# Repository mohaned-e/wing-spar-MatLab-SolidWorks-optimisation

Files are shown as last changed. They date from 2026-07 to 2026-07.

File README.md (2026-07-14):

# Automated Wing Spar Design: MATLAB Structural Optimisation with SolidWorks FEA Validation

An automated tool that designs a minimum-mass, geometrically-valid box spar for a foam-board UAV wing — sizing it against bending, torsion, and the real NACA aerofoil envelope — then validates the result against SolidWorks FEA.

Built as a self-directed project by an Aerospace Engineering undergraduate at the University of Manchester, extending a university structural design exercise (originally taught using a manual Excel spreadsheet and hand iteration) into a fully automated MATLAB pipeline.

---

## Background: from manual design to automation

This project began as a manual, hand-iterated structural design exercise — sizing a wing spar in Excel by adjusting dimensions until the stress and torsion checks passed, then building and physically load-testing the result. That original project is documented here:

**[▶ Original manual Wing Spar Design — physical build & load test](https://youtu.be/0Efimh8G1TI?si=opNGgLY5TrZkc-P6)**

Every constraint and validation check in this automated MATLAB version (bending stress, torsional compliance, geometric fit, physical safety margin) traces directly back to lessons learned building and testing that first version by hand.

---

## What this project does

Given a target wing (span, aerofoil, load case), the tool:

1. **Models the bending moment** distribution along the wing under a specified load factor.
2. **Sizes a hollow box-section spar** — height, width, and wall thickness — searching thousands of candidate cross-sections to find the **lightest one** that satisfies:
   - Bending stress (reserve factor ≥ 1)
   - Torsional stiffness (twist compliance ≤ 3°/N·m)
   - **Fits inside the real NACA aerofoil shape**, across the spar's full width — not just at a single point
   - A genuine manufacturing safety margin (real, physical clearance — not a mathematical edge case)
3. **Generates the aerofoil geometry from scratch** using the standard NACA 4-digit equations (thickness distribution + camber line + perpendicular surface offset) — no external aerofoil coordinate database used.
4. **Exports the aerofoil coordinates** in a format SolidWorks can import directly (`Insert → Curve → Curve Through XY Points`).
5. **Calculates the spar's exact position** — both chordwise and vertically — accounting for the aerofoil's camber, so the spar sits correctly inside the wing rather than being naively centred on the chord line.
6. **Validates the design against SolidWorks FEA**, comparing MATLAB's analytical predictions (deflection, bending stress) against a real finite element simulation of the built geometry.

---

## Repository structure

```
/matlab/
    wing_spar_optimisation.m         — main optimiser (bending + torsion + aerofoil fit)
    NACA_airofoil_coordinates.m      — NACA 4-digit aerofoil generator & SolidWorks export
    local_aerofoil_height.m          — aerofoil upper/lower surface height at a given chord position
/solidworks/
    Wing_Geometry_Master_Sketch.SLDPRT
    Rib.SLDPRT
    Spar.SLDPRT
    Rear_Spar.SLDPRT
    leading_edge.SLDPRT
    Flaps.SLDPRT
    Spar_holder.SLDPRT
    wing_assembly.SLDASM
/aerofoil_data/
    naca4418.txt                     — exported aerofoil coordinates (tab-delimited X Y Z, for SolidWorks import)
/results/
    Full_Wing_Design.png
    Aerofoil_Graph.png
    Bending_Displacment_Test.png
    Bending_Stress_Test.png
    Torisional_Stress_test.png
README.md
```

---

## Methodology

### 1. Structural model
The wing is modelled as a cantilever beam, fixed at the root, carrying a point load at the tip (`load factor × aircraft mass × g / 2`). The spar is a hollow rectangular box section; bending stress, tip deflection, and torsional twist are calculated from standard beam theory (second moment of area, Bredt-Batho thin-wall torsion theory).

### 2. Optimisation
A nested search over height, width, top/bottom wall thickness, and side wall thickness finds the lightest cross-section that passes all structural checks *and* physically fits inside the aerofoil. Wall thickness was deliberately included as a free variable rather than fixed — the optimiser correctly converged on the material's minimum manufacturable thickness (5mm foam board) in every case, consistent with the general aerospace engineering principle that thin-walled sections are structurally efficient (material is placed as far as possible from the neutral axis, rather than adding mass near the centre where it contributes little to stiffness). This is a genuine, expected result rather than an unused design variable — see "Known limitations" for the one check (local buckling) that would be needed to make thickness a meaningful trade-off rather than always bottoming out.

### 3. Aerofoil geometry
The NACA 4-digit thickness and camber equations are implemented directly (not pulled from a lookup table), including the correct perpendicular offset of the thickness distribution relative to the camber line — a detail that's easy to get wrong by simply adding thickness vertically instead of normal to the curve.

### 4. Geometric fit validation
An early version of the optimiser checked whether the spar fit the aerofoil at a single chordwise point. This was found — through direct visual inspection in SolidWorks — to be insufficient: because the aerofoil tapers away from its point of maximum thickness, a wide spar's *corners* can clip the surface even when its centre clears comfortably. The constraint was rebuilt to check the aerofoil envelope across the spar's full width, taking the tightest top and bottom limits independently (which can come from different edges of the spar).

---

## Results: MATLAB prediction vs. SolidWorks FEA

Final design: **38mm × 92mm** box spar, 5mm walls, positioned 90mm from the leading edge and 8.88mm above the chord line, tested over a 755mm free (unsupported) length.

| Quantity | MATLAB predicted | SolidWorks FEA (actual) | Note |
|---|---|---|---|
| Tip deflection (6.74N tip load) | 19.86 mm | 20.6 mm | Close agreement — **3.7% difference** |
| Peak bending stress (6.74N tip load) | 357.4 kPa | 538.9 kPa* | 50.8% higher — local effect, see below |
| Torsional twist (10 N·m reference torque) | ≤30° (design limit, not a point prediction) | 10° | Real design sits well inside the limit, see below |

\* *The FEA peak stress occurs at the vice grip interface at the root — a local stress concentration from the clamping mechanism that simple beam theory does not model. Deflection, a whole-beam property averaged over the full structure, is far less sensitive to this kind of local effect and shows strong agreement; stress, being highly local, diverges specifically at this known geometric discontinuity. This is consistent with the failure location predicted qualitatively in the source structural design methodology this project extends.*

**On the torsion result**: the optimiser doesn't target 30° as a predicted outcome — it's the *compliance limit* (≤3°/N·m at the reference 10 N·m torque) the design is required to satisfy, and the optimiser deliberately searches for the lightest spar that sits right at that boundary (calculated compliance ≈2.999°/N·m, essentially on the limit by design). The measured real-world twist (10°) is roughly 3x lower than that worst-case limit — a reassuring result, not a discrepancy to explain away. The gap itself is attributable to the analytical torsion model (Bredt-Batho thin-wall theory) being a conservative approximation: it assumes an idealised infinitely-thin wall, whereas the real wall thickness is a non-trivial fraction of the section (13% of the height), which stiffens the real structure beyond what the thin-wall formula accounts for. Being wrong in this direction — predicting more twist than actually occurs — is the safe direction for a structural design margin to be wrong in.

Spar mass was cross-checked against SolidWorks' own mass properties calculation: once the difference in physical length was accounted for (MATLAB assumed a full-span length for its mass estimate; the SolidWorks test-rig spar was built to the full foam board sheet length for practical clamping purposes), the predicted mass-per-unit-length matched SolidWorks' reported value to six significant figures — confirming the cross-sectional geometry transferred from MATLAB into CAD with no error.

---

## Known limitations / not yet implemented

- **Local panel buckling is not modelled.** The optimiser checks material stress and torsional stiffness, but not whether the thin top/bottom panels could buckle (a stability failure) before the material stress limit is reached. Given the optimiser already converges on the thinnest available wall thickness, this is the most significant open extension to this project — likely via a SolidWorks Buckling study on the final geometry, since implementing a panel buckling formula analytically would require additional assumptions this project doesn't currently make (panel aspect ratio, edge support conditions).
- **The torsional twist angle was measured directly off the deformed model** (viewed straight down the twist axis, true-scale deflection) rather than via a SolidWorks angular displacement output, so it should be treated as a good estimate rather than an instrument-grade measurement.

---

## Requirements

- MATLAB (no additional toolboxes required — `fminsearch`/manual search loops only, `writematrix` requires R2019a+)
- SolidWorks (used for geometry import, assembly, and FEA — Student Edition sufficient)

## Author

Mohaned Elkurdi — MEng Aerospace Engineering, University of Manchester

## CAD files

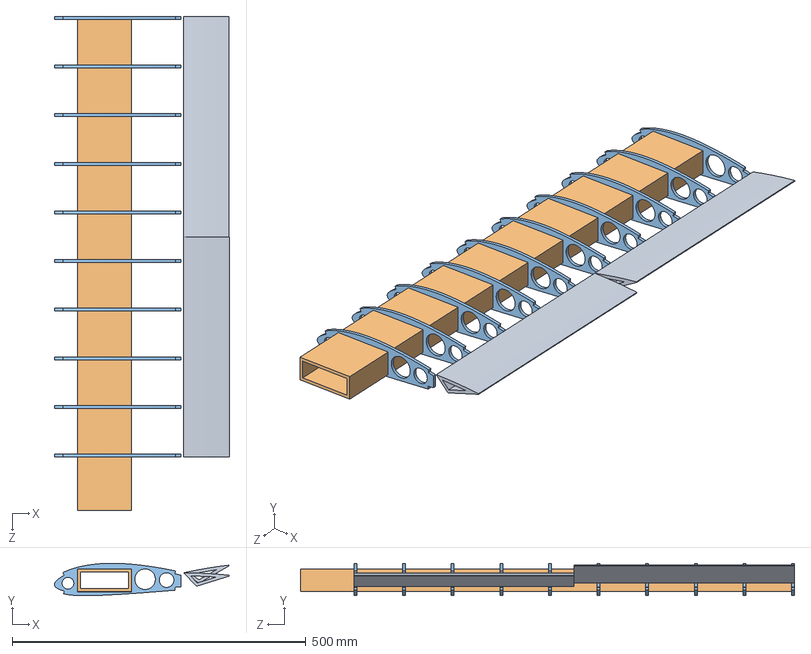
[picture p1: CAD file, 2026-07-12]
solidworks/Wing_Assembly.SLDASM
298.5 x 55.3 x 841.0 mm
Rib x 10
Spar
Flaps x 2

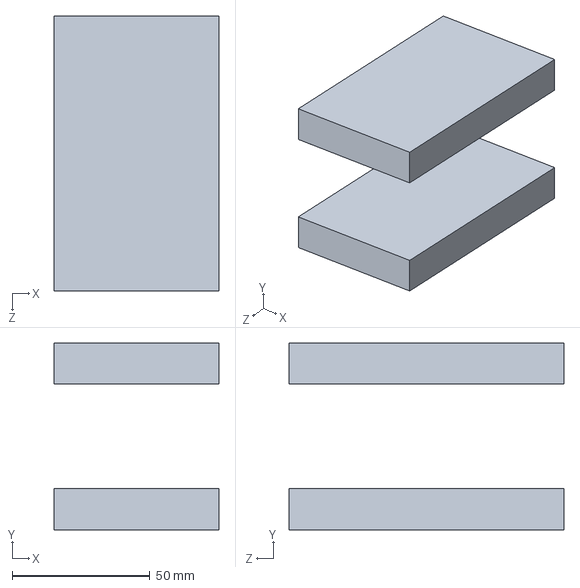
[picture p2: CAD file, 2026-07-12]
solidworks/Spar_Holder.SLDPRT
60.0 x 68.0 x 100.0 mm

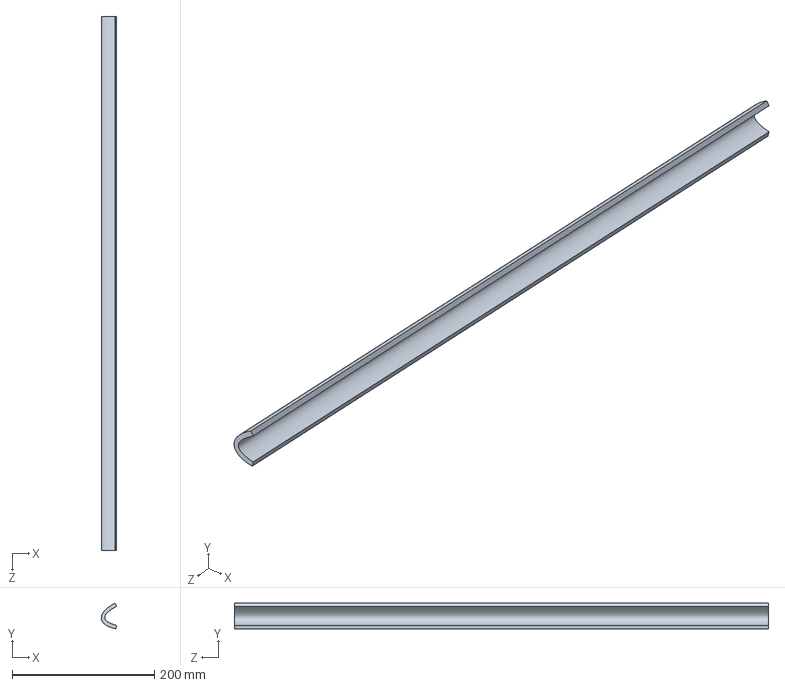
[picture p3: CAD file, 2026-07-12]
solidworks/Leading_Edge.SLDPRT
21.7 x 36.2 x 750.0 mm

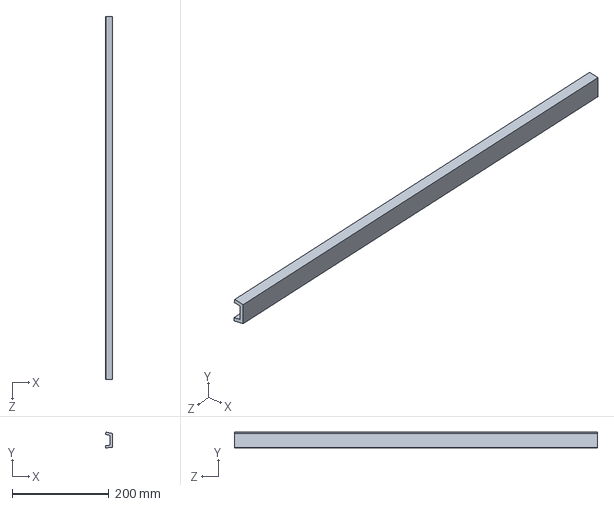
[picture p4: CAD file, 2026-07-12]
solidworks/Rear_Spar.SLDPRT
15.1 x 32.8 x 750.0 mm

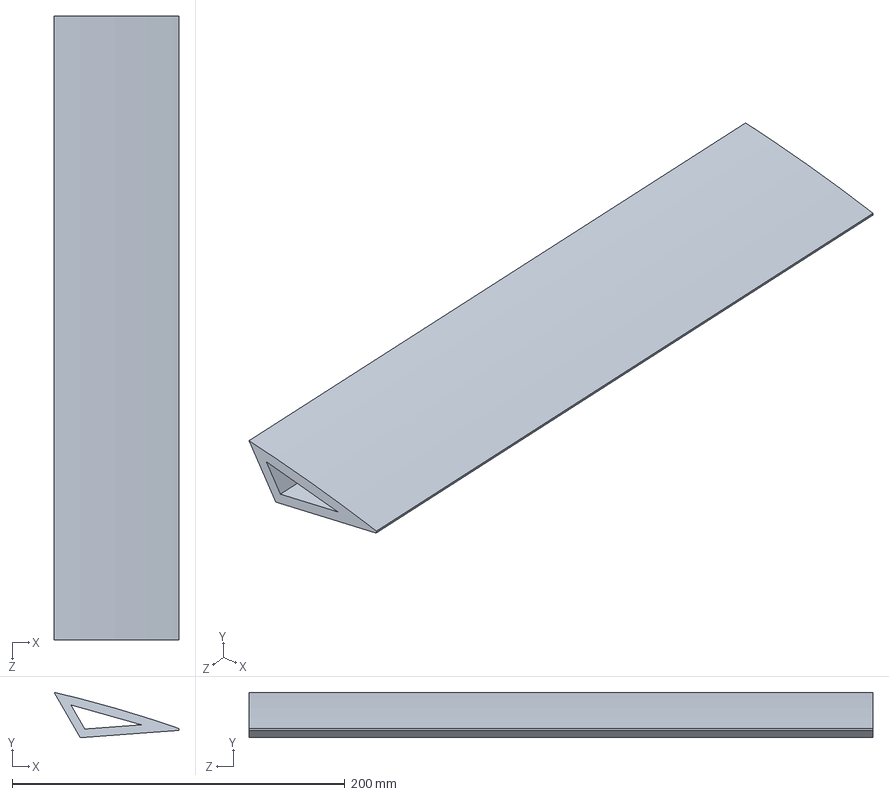
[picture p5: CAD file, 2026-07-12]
solidworks/Flaps.SLDPRT
75.1 x 27.3 x 375.0 mm

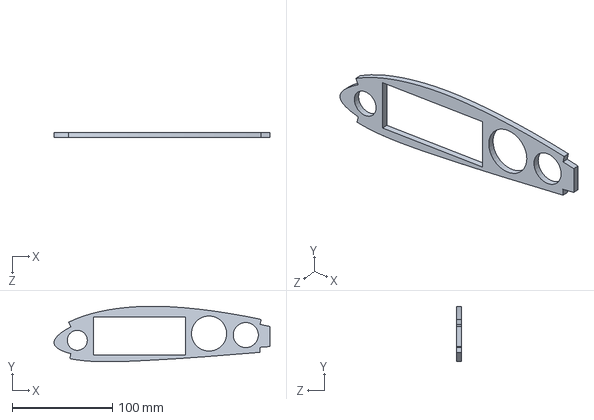
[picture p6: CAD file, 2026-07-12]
solidworks/Rib.SLDPRT
215.2 x 55.3 x 5.00 mm

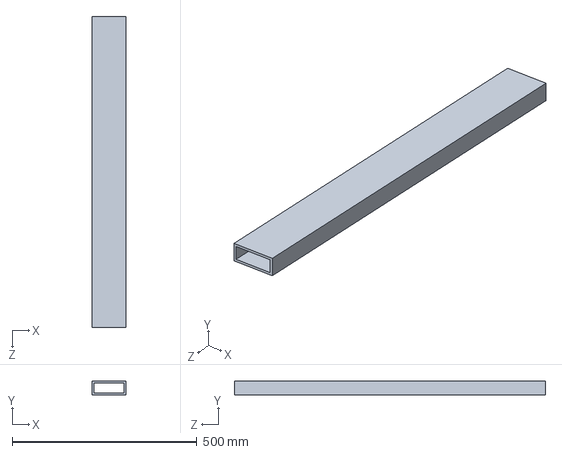
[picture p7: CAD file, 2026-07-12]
solidworks/Spar.SLDPRT
92.0 x 38.0 x 841.0 mm

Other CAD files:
solidworks/Wing_Geometry_Master_Sketch.SLDPRT

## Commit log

2026-07-12 Rename Rear Spar.SLDPRT to solidworks/Rear_Spar.SLDPRT
    [Rear_Spar.SLDPRT]
2026-07-12 Rename Spar holder.SLDPRT to solidworks/Spar_Holder.SLDPRT
    [Spar_Holder.SLDPRT]
2026-07-12 Rename Wing Geometry Master Sketch.SLDPRT to solidworks/Wing_Geometry_Master_Sketch.SLDPRT
    [Wing_Geometry_Master_Sketch.SLDPRT]
2026-07-12 Rename wing assembly.SLDASM to solidworks/Wing_Assembly.SLDASM
    [Wing_Assembly.SLDASM]
2026-07-12 Rename leading edge.SLDPRT to solidworks/Leading_Edge.SLDPRT
    [Leading_Edge.SLDPRT]
